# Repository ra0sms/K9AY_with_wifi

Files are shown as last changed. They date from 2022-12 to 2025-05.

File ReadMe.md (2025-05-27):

# K9AY receiving loop with Wi-Fi control

This antenna has 8 directions and switchable Load resistor

* Based on ESP8266 (esp-12 module with external Wi-Fi antenna)
* 2 loops and 8 directions
* Need only one power supply (12-13.8VDC, 500mA)
* Control via any web-browser
* Source code for Arduino IDE

More information about loop and construction details - https://ra0sms.com/k9ay-wifi-interface/

[Latest schematic version](KiCad/K9AY_switch/K9AY_switch.pdf)

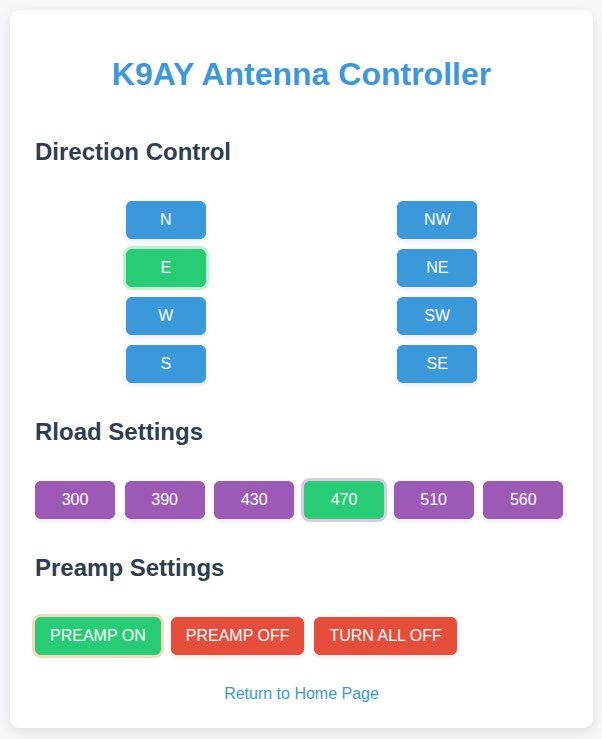
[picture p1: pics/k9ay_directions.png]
k9ay_directions


------

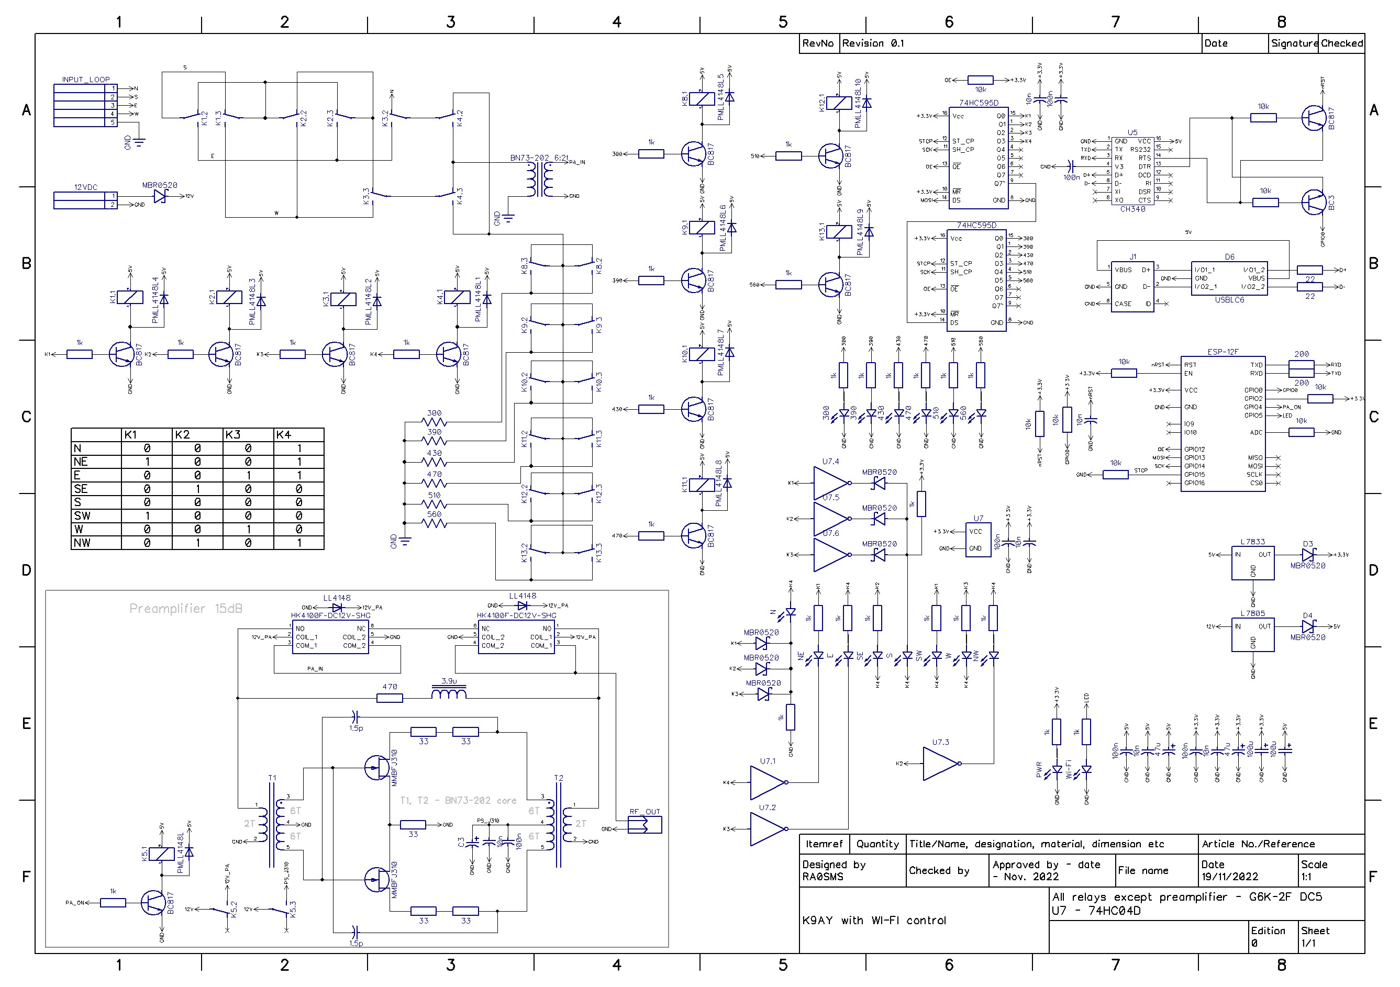
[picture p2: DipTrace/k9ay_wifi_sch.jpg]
Schematic


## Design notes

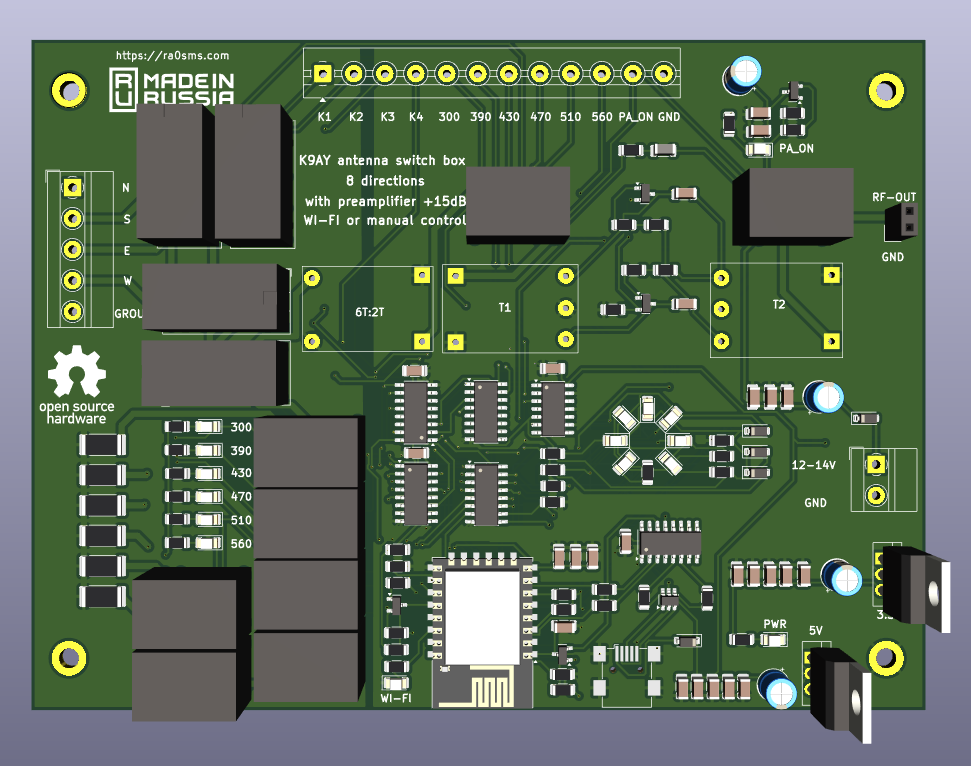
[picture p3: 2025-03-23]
KiCad/K9AY_switch/3d_1.png

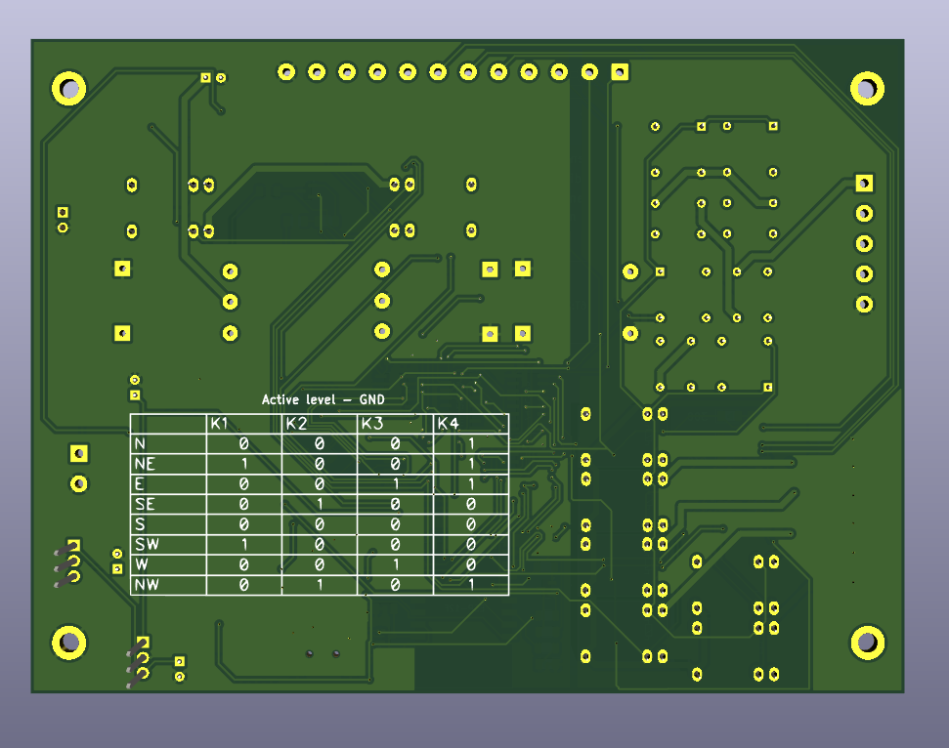
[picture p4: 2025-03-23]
KiCad/K9AY_switch/3d_2.png

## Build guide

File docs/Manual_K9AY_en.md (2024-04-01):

# Instructions for setting up K9AY control box with WI-FI interface

* External input voltage: 12V or 13.8V
* Consumption current: 200 mA
* The screw terminals **N S E W** is used to connect loops
* The screw terminal **GROUND** is used to connect radials
* WI-FI range - up to 50m when using an entry-level WI-FI router  
* Case dimensions - 170 * 120 * 55 mm. ABS plastic, degree of protection IP68, cable glands for diameter of 3 to 7 mm
* The name of the WI-FI network: **`K9AY_Loop_sn__`**  
* Access point network password: **1234567890** 
* IP address of the web server on the `K9AY_Loop_sn__` network: **192.168.4.1**  
* Links for access:
  * `192.168.4.1/wifi` – wifi settings 
  * `192.168.4.1/switch` – page for switch  
  * `192.168.4.1` – start page

Before you start setting up, your router must have **DHCP enabled!**  

When you first turn on, you need to connect the controller to your WI-FI network. To do this, you must search for available networks on your smartphone or computer. The switch creates a network `K9AY_Loop_sn__`.

After connecting the network, go to the web browser at `http://192.168.4.1/wifi`. A window with WI-FI settings will open. You must enter the name and password of your router network and click "Connect / Disconnect" button.

After that, at the page `http://192.168.4.1/wifi` you can see the IP address of the device in your WI-FI network. Now that the switch is connected to your network, you can disconnect from the `K9AY_Loop_sn__` network. Further, to access the switch's web server, use the IP address issued by your WI-FI router.

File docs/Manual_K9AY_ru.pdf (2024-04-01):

ra0sms.shop

### Инструкция по настройке контроллера управления приемной антенной K9AY с Wi-Fi интерфейсом

- Напряжение внешнего источника питания – 12(13,8)В.
- Потребляемый ток – 250 мА.
- Винтовые клеммы N S E W – для подключения взаимно перпендикулярных рамок, ориентированных на Север-Юг и Восток-Запад.
- Винтовая клемма GROUND – для подключения системы противовесов.
- Радиус действия – до 50м при использовании WI-FI роутера начального уровня
- Размеры корпуса – 170*120*55 мм. Пластик ABS, степень защиты IP68, вводы для кабеля диаметром от 3 до 7 мм
- Имя создаваемой WI-FI сети – «K9AY_Loop_sn___»
- Пароль к сети – «1234567890»
- IP адрес web сервера в сети «K9AY_Loop_sn___» – 192.168.4.1

Адреса для доступа:
192.168.4.1/wifi – страница настроек подключения в Вашей WI-FI сети 192.168.4.1/switch – страница управления контроллером 192.168.4.1 – стартовая страница веб-сервера

Перед началом настройки на вашем роутере должен быть включен DCHP!

При первом включении необходимо подключить контроллер к вашей сети WI-FI. Для этого необходимо выполнить поиск доступных сетей на смартфоне либо компьютере. Контроллер создает сеть "K9AY_Loop_sn__" пароль "1234567890".

После подключения сети необходимо перейти в веб-браузере по адресу "http://192.168.4.1/wifi" . Откроется окно с настройками WI-FI. Необходимо ввести имя и пароль вашей сети и нажать кнопку "Connect/Disconnect"

После этого по адресу "http://192.168.4.1/wifi" можно увидеть IP адрес устройства в вашей WI-FI сети. Теперь, когда контроллер подключен к вашей сети, можно отключиться от сети "K9AY_Loop_sn__". При успешном подключении к вашей WI-FI сети должен загореться светодиод “WIFI”. Далее для доступа к веб серверу контроллера используйте IP адрес, выданный вашим WI-FI роуетром.

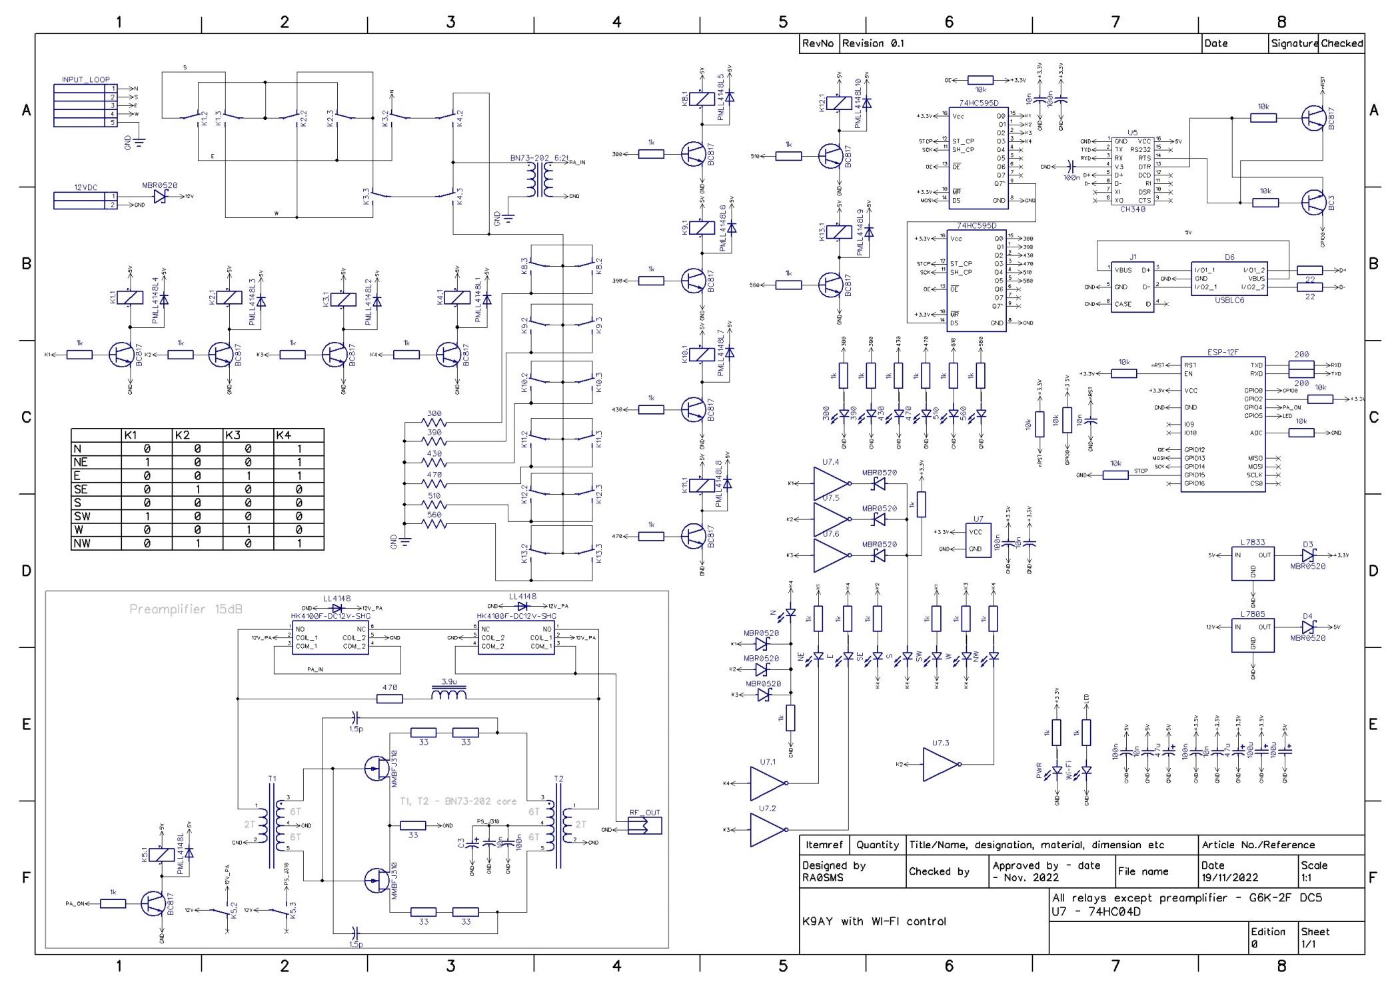
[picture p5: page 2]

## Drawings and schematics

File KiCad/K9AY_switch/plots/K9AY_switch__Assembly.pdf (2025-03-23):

## 8 directions WI-FI or manual control with preamplifier +15dB

## K9AY antenna switch box

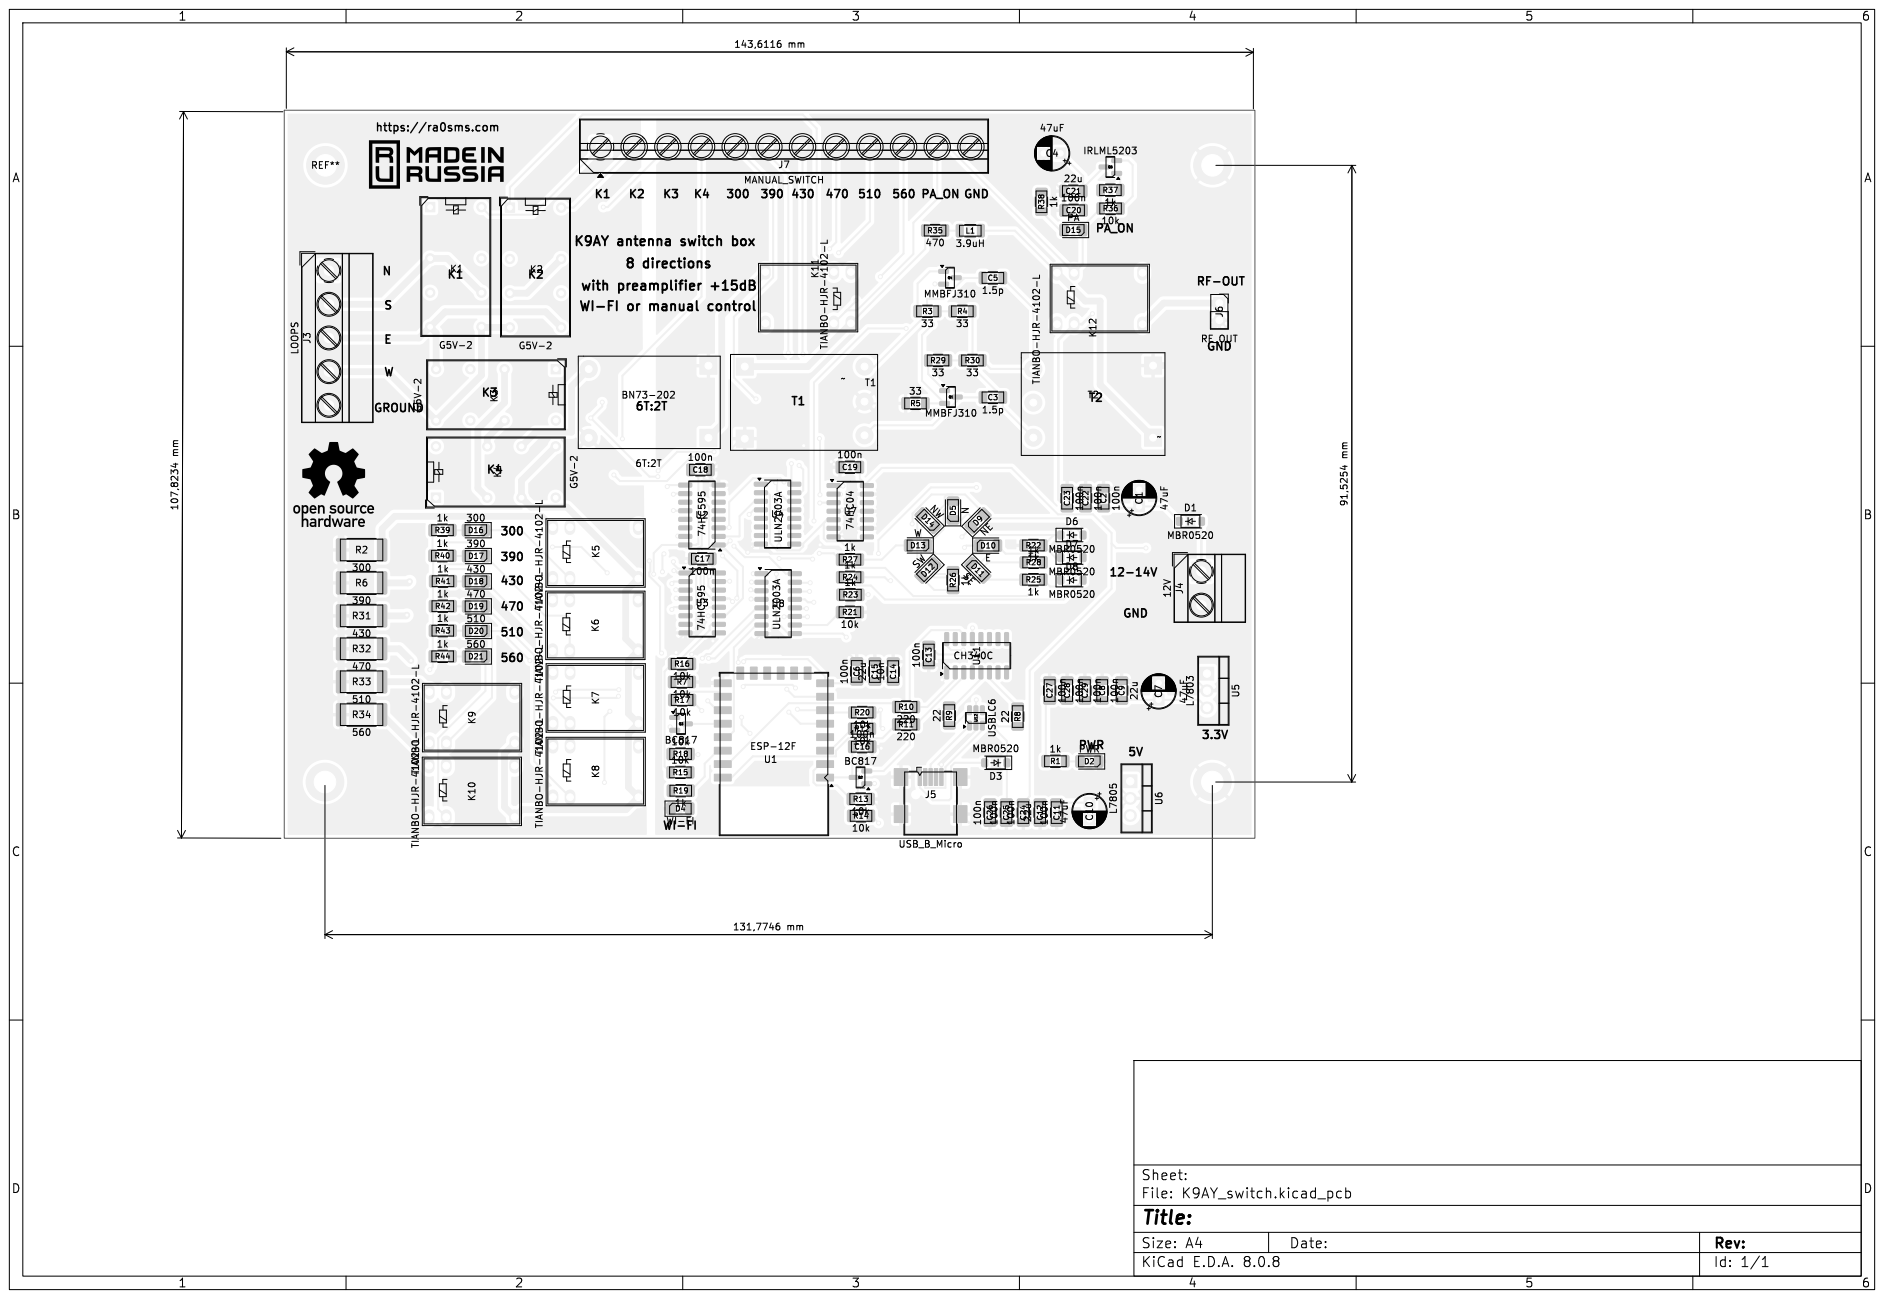
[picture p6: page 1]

1 | 2 | 3 | 4 | 5 | 6

A

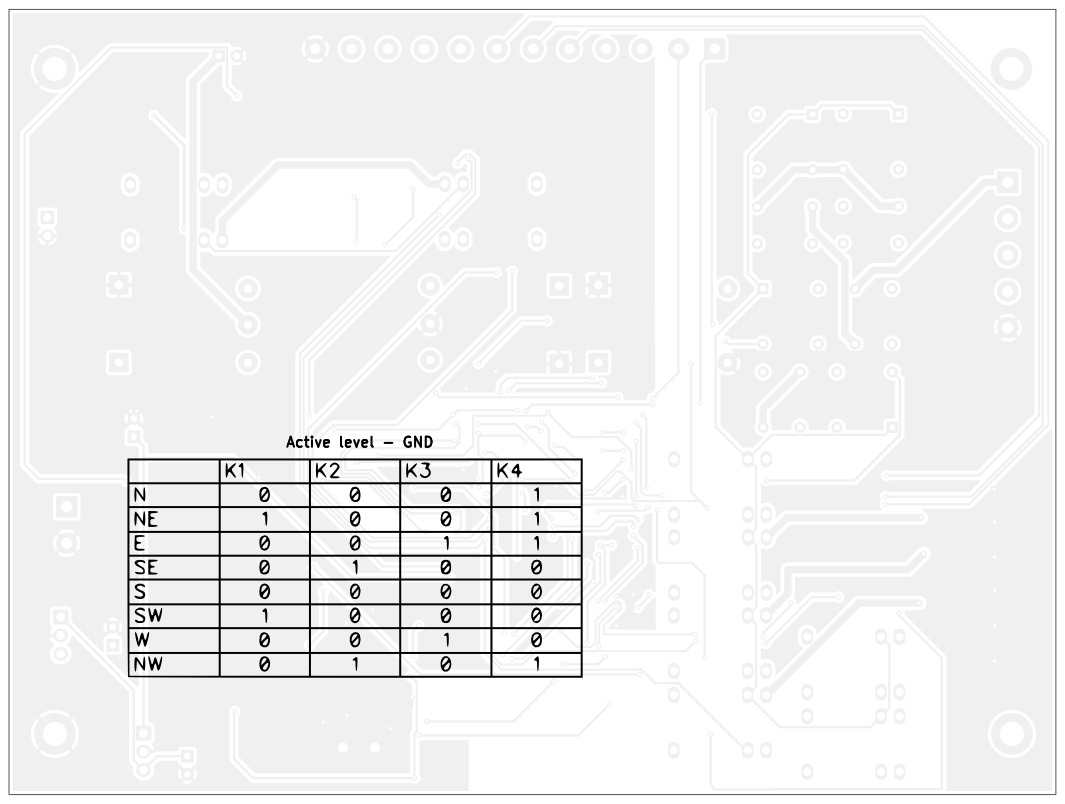
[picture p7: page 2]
D Date: KiCad; E.D.A. 8.0.8 Size: A4; Rev:

Active level - GND

Id: 1/1 Title: File: K9AY_switch.kicad_pcb Sheet:

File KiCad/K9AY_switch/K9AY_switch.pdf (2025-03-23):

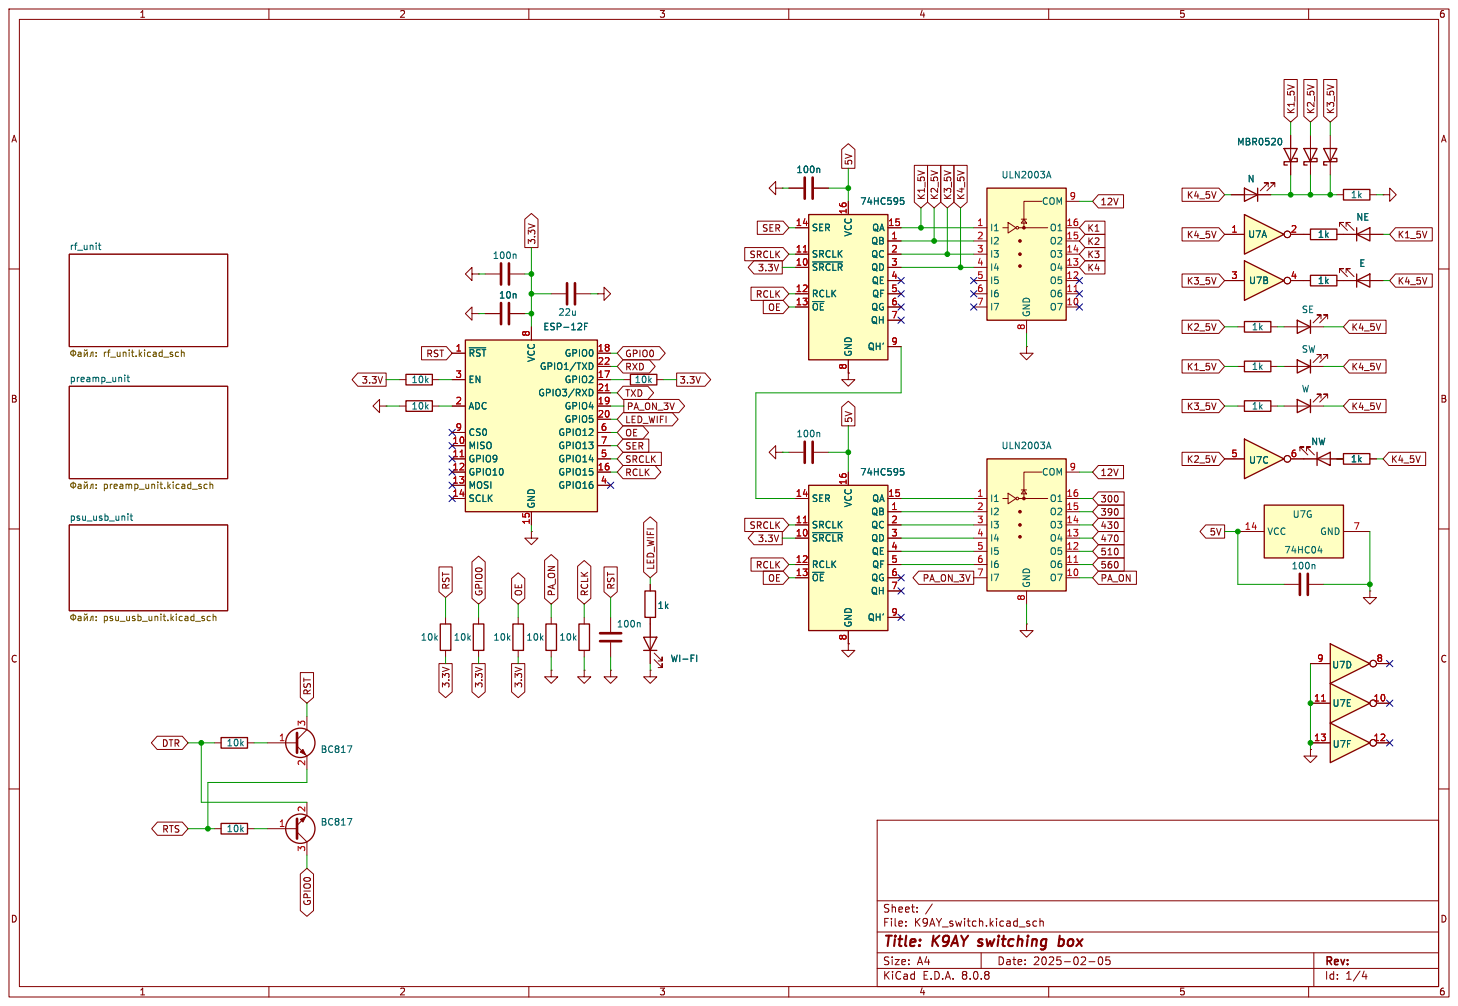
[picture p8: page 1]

2 3 BC817 QB 1 ~{SRCLR} 10 SRCLK 11 RCLK 12 ~{OE} 13 SER 14 QA 15 VCC 16 QC 2 QD 3 QE 4 QF 5 QG 6 QH 7 GND

File: K9AY_switch.kicad_sch Sheet: /
Id: 1/4 Title: K9AY switching box

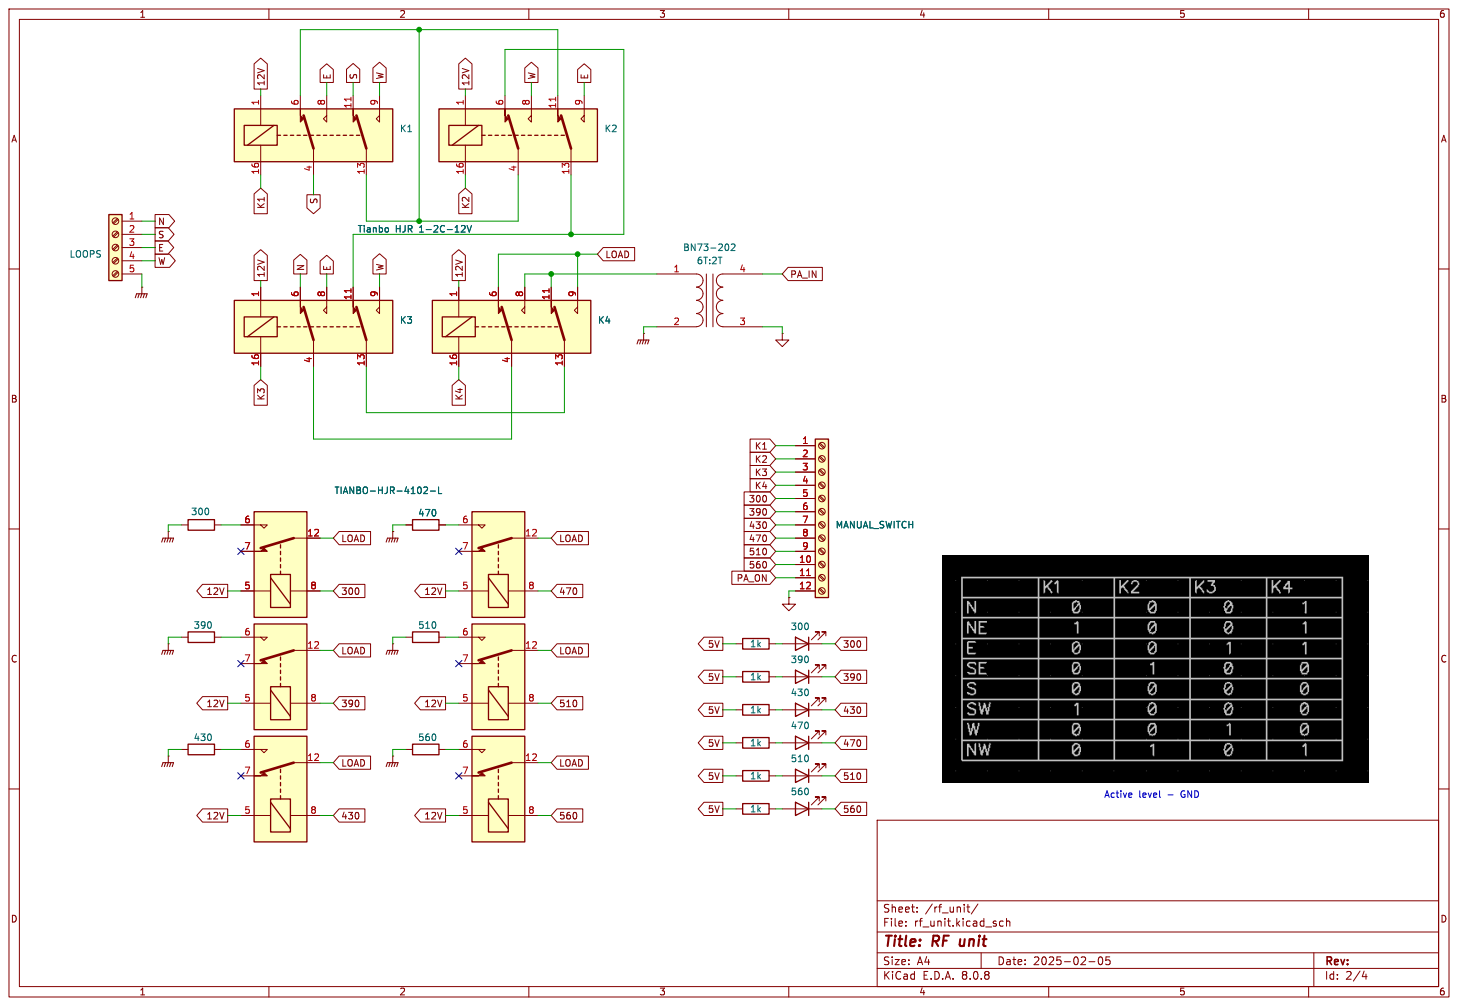
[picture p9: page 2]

Id: 2/4 Title: RF unit File: rf_unit.kicad_sch Sheet: /rf_unit/ 390

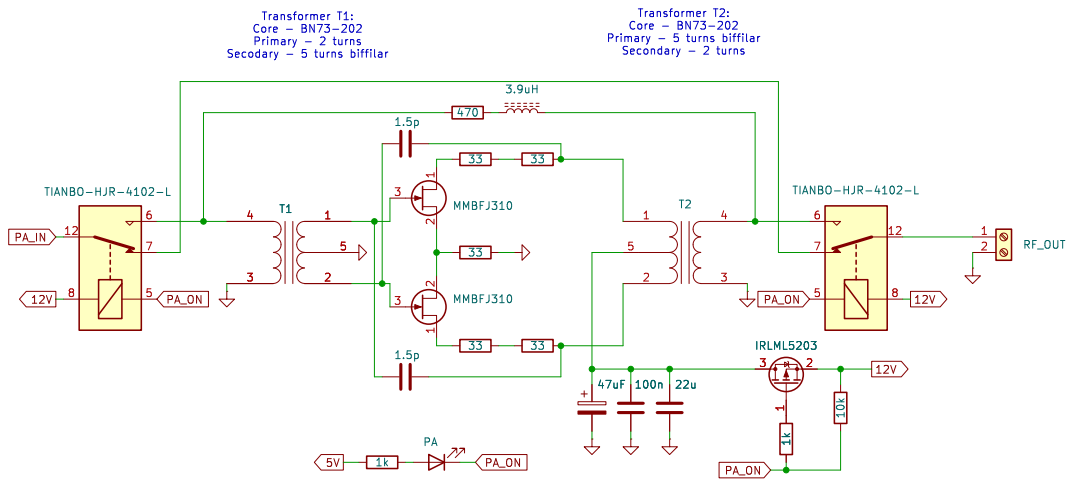
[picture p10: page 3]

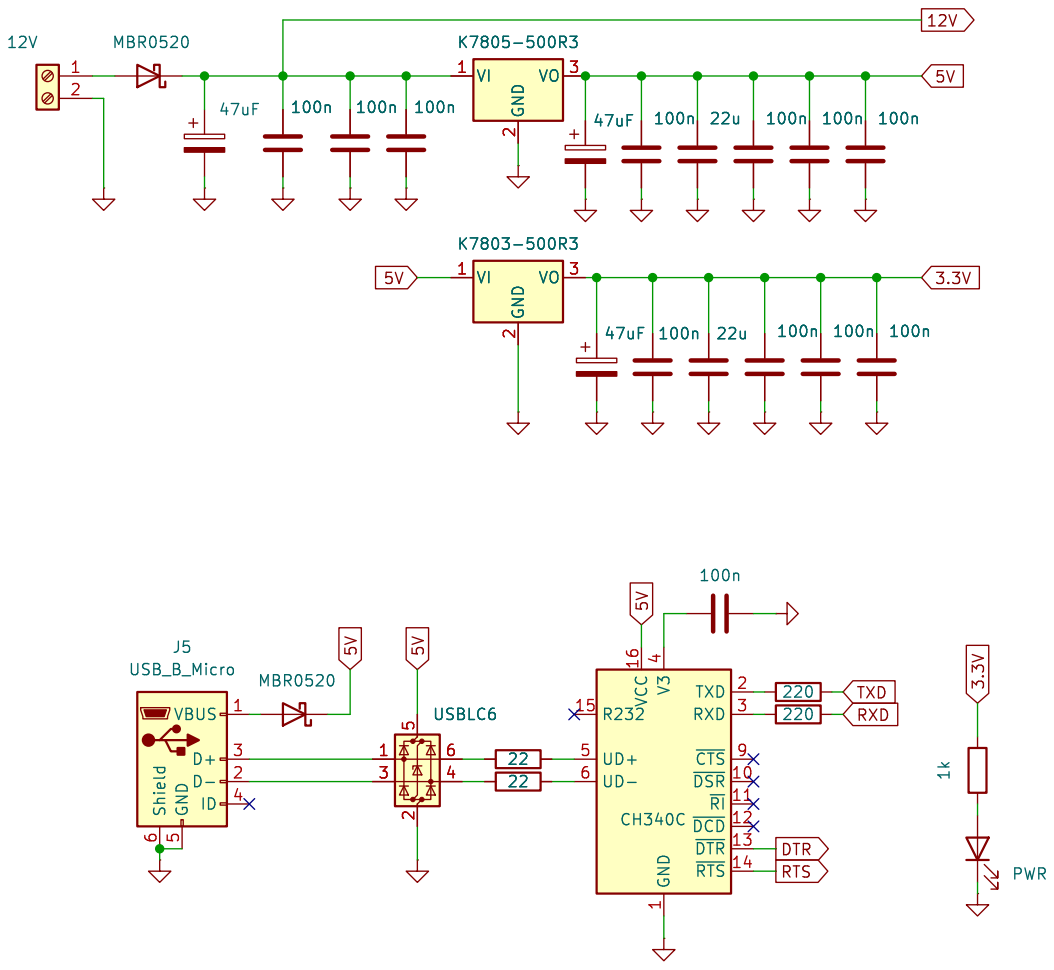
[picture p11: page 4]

1 ~{DSR} 10 ~{RI} 11 ~{DCD} 12 ~{DTR} 13 ~{RTS} 14 R232 15 VCC 16 TXD 2 RXD 3 V3

Id: 4/4 Title: Power supply and USB connection unit File: psu_usb_unit.kicad_sch Sheet: /psu_usb_unit/

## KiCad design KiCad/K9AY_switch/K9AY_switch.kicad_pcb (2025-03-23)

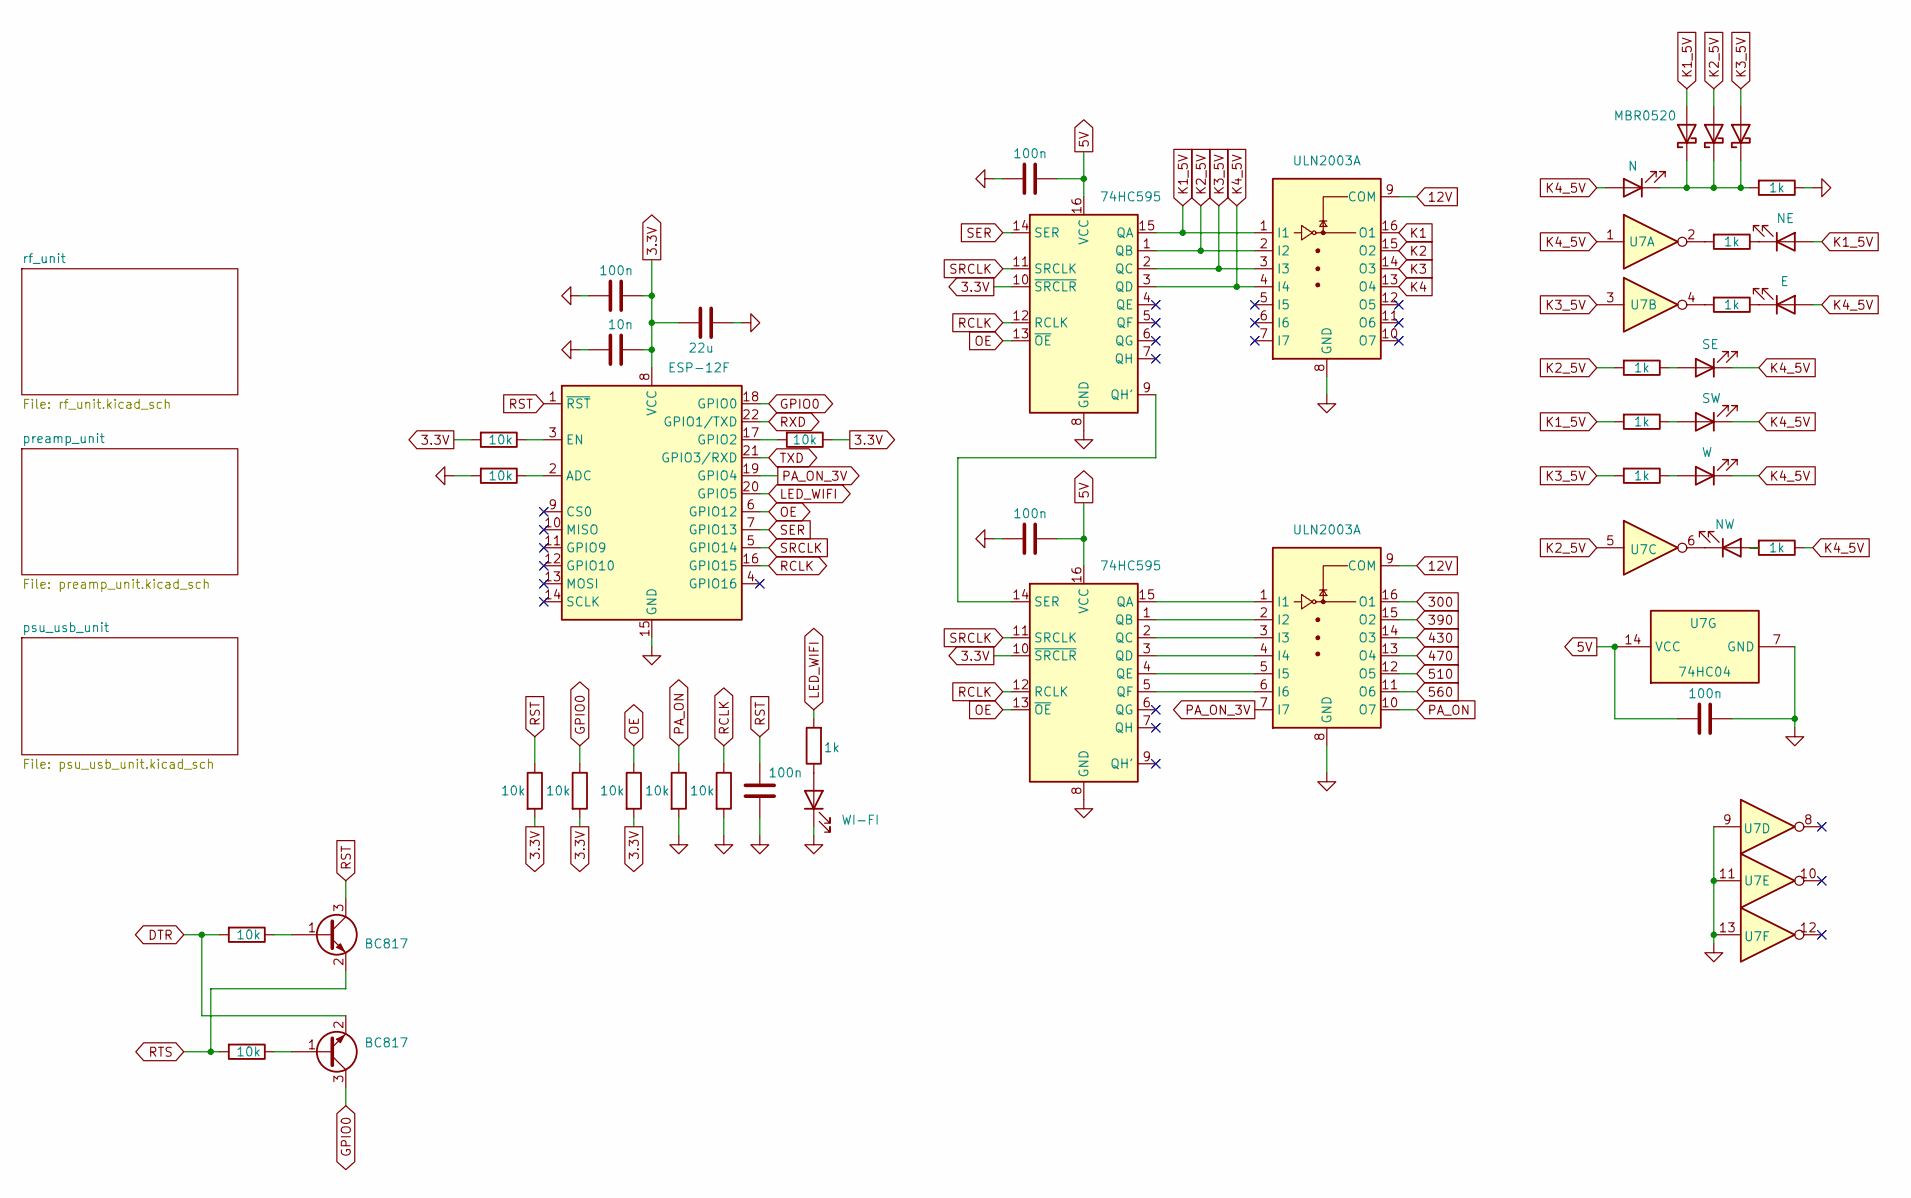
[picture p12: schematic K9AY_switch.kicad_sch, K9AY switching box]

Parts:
C6, C16, C17, C18, C19: 100n; C_1206_3216Metric
C14: 10n; C_1206_3216Metric
C15: 22u; C_1206_3216Metric
D4: WI-FI; LED_1206_3216Metric
D5: N; LED_1206_3216Metric
D6, D7, D8: MBR0520; D_SOD-123
D9: NE; LED_1206_3216Metric
D10: E; LED_1206_3216Metric
D11: SE; LED_1206_3216Metric
D12: SW; LED_1206_3216Metric
D13: W; LED_1206_3216Metric
D14: NW; LED_1206_3216Metric
Q2, Q3: BC817; SOT-23
R7, R12, R13, R14, R15, R16, R17, R18, R20, R21: 10k; R_1206_3216Metric
R19, R22, R23, R24, R25, R26, R27, R28: 1k; R_1206_3216Metric
U1: ESP-12F; ESP-12E
U2, U3: 74HC595; SOIC-16_3.9x9.9mm_P1.27mm
U4, U8: ULN2003A; SOIC-16_3.9x9.9mm_P1.27mm
U7: 74HC04; SOIC-14_3.9x8.7mm_P1.27mm

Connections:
3.3V: C6.2, C14.2, C15.2, R12.2, R14.2, R15.2, R16.1, R20.2, U1.8 (VCC), U2.10 (~SRCLR), U3.10 (~SRCLR); also elsewhere on the board
5V: C17.2, C18.2, C19.1, U2.16 (VCC), U3.16 (VCC), U7.14 (VCC); also elsewhere on the board
12V: U4.9 (COM), U8.9 (COM); also elsewhere on the board
300: U8.16 (O1); also elsewhere on the board
390: U8.15 (O2); also elsewhere on the board
430: U8.14 (O3); also elsewhere on the board
470: U8.13 (O4); also elsewhere on the board
510: U8.12 (O5); also elsewhere on the board
560: U8.11 (O6); also elsewhere on the board
DTR: Q3.2 (E), R18.2; also elsewhere on the board
GND: C6.1, C14.1, C15.1, C16.1, C17.1, C18.1, C19.2, D4.1 (K), R7.2, R13.2, R21.2, R22.1, U1.15 (GND), U2.8 (GND), U3.8 (GND), U4.8 (GND), U7.7 (GND), U7.9, U7.11, U7.13, U8.8 (GND); also elsewhere on the board
GPIO0: Q3.3 (C), R15.1, U1.18 (GPIO0)
K1: U4.16 (O1); also elsewhere on the board
K1_5V: D6.2 (A), D9.2 (A), R26.2, U2.15 (QA), U4.1 (I1)
K2: U4.15 (O2); also elsewhere on the board
K2_5V: D7.2 (A), R25.2, U2.1 (QB), U4.2 (I2), U7.5
K3: U4.14 (O3); also elsewhere on the board
K3_5V: D8.2 (A), R27.2, U2.2 (QC), U4.3 (I3), U7.3
K4: U4.13 (O4); also elsewhere on the board
K4_5V: D5.2 (A), D10.2 (A), D11.1 (K), D12.1 (K), D13.1 (K), R28.1, U2.3 (QD), U4.4 (I4), U7.1
LED_WIFI: R19.2, U1.20 (GPIO5)
unnamed: D4.2 (A), R19.1
unnamed: D5.1 (K), D6.1 (K), D7.1 (K), D8.1 (K), R22.2
unnamed: D9.1 (K), R23.1
unnamed: D10.1 (K), R24.1
unnamed: D11.2 (A), R25.1
unnamed: D12.2 (A), R26.1
unnamed: D13.2 (A), R27.1
unnamed: D14.2 (A), R28.2
unnamed: D14.1 (K), U7.6
unnamed: Q2.1 (B), R18.1
unnamed: Q3.1 (B), R17.1
unnamed: R23.2, U7.2
unnamed: R24.2, U7.4
unnamed: R13.1, U1.2 (ADC)
unnamed: R12.1, U1.3 (EN)
unnamed: R16.2, U1.17 (GPIO2)
unnamed: U2.9 (QH'), U3.14 (SER)
unnamed: U3.15 (QA), U8.1 (I1)
unnamed: U3.1 (QB), U8.2 (I2)
unnamed: U3.2 (QC), U8.3 (I3)
unnamed: U3.3 (QD), U8.4 (I4)
unnamed: U3.4 (QE), U8.5 (I5)
unnamed: U3.5 (QF), U8.6 (I6)
OE: R20.1, U1.6 (GPIO12), U2.13 (~OE), U3.13 (~OE)
PA_ON: R21.1, U8.10 (O7); also elsewhere on the board
PA_ON_3V: U1.19 (GPIO4), U8.7 (I7)
RCLK: R7.1, U1.16 (GPIO15), U2.12 (RCLK), U3.12 (RCLK)
RST: C16.2, Q2.3 (C), R14.1, U1.1 (~RST)
RTS: Q2.2 (E), R17.2; also elsewhere on the board
RXD: U1.22 (GPIO1/TXD); also elsewhere on the board
SER: U1.7 (GPIO13), U2.14 (SER)
SRCLK: U1.5 (GPIO14), U2.11 (SRCLK), U3.11 (SRCLK)
TXD: U1.21 (GPIO3/RXD); also elsewhere on the board

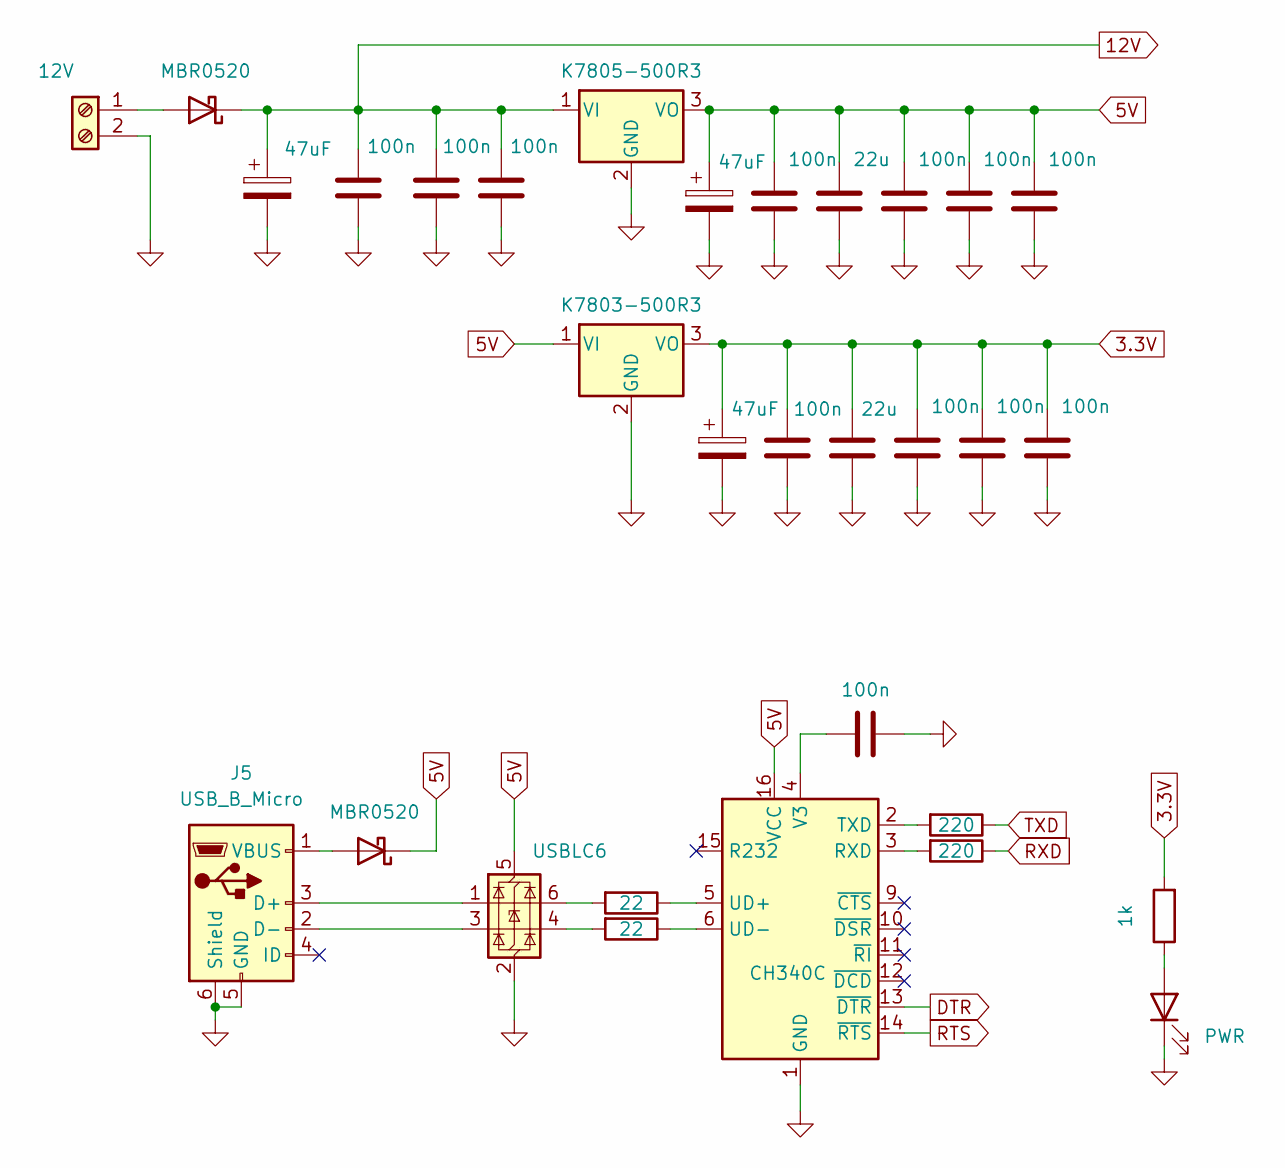
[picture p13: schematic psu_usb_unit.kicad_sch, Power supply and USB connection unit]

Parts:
C1, C7, C10: 47uF; CP_Radial_D5.0mm_P2.50mm
C2, C8, C11, C13, C22, C23, C24, C25, C26, C27, C28, C29: 100n; C_1206_3216Metric
C9, C12: 22u; C_1206_3216Metric
D1, D3: MBR0520; D_SOD-123
D2: PWR; LED_1206_3216Metric
J4: 12V; TerminalBlock_MetzConnect_Type011_RT05502HBWC_1x02_P5.00mm_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
J5: USB_B_Micro; USB_Mini-B_Wuerth_65100516121_Horizontal
R1: 1k; R_1206_3216Metric
R8, R9: 22; R_1206_3216Metric
R10, R11: 220; R_1206_3216Metric
U5: K7803-500R3; TO-220-3_Vertical
U6: K7805-500R3; TO-220-3_Vertical
U11: CH340C; SOIC-16_3.9x9.9mm_P1.27mm
U12: USBLC6; SOT-23-6

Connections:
3.3V: C7.1, C8.1, C9.1, C27.1, C28.1, C29.1, R1.2, U5.3 (VO); also elsewhere on the board
5V: C10.1, C11.1, C12.1, C24.1, C25.1, C26.1, D3.1 (K), U5.1 (VI), U6.3 (VO), U11.16 (VCC), U12.5 (VBUS); also elsewhere on the board
12V: C1.1, C2.1, C22.1, C23.1, D1.1 (K), U6.1 (VI); also elsewhere on the board
DTR: U11.13 (~DTR); also elsewhere on the board
GND: C1.2, C2.2, C7.2, C8.2, C9.2, C10.2, C11.2, C12.2, C13.2, C22.2, C23.2, C24.2, C25.2, C26.2, C27.2, C28.2, C29.2, D2.1 (K), J4.2, J5.5 (GND), J5.6 (Shield), U5.2 (GND), U6.2 (GND), U11.1 (GND), U12.2 (GND); also elsewhere on the board
unnamed: D1.2 (A), J4.1
unnamed: D2.2 (A), R1.1
unnamed: D3.2 (A), J5.1 (VBUS)
unnamed: J5.3 (D+), U12.1 (I/O1)
unnamed: J5.2 (D-), U12.3 (I/O2)
unnamed: R8.2, U12.4 (I/O2)
unnamed: R9.2, U12.6 (I/O1)
unnamed: R11.2, U11.3 (RXD)
unnamed: R10.2, U11.2 (TXD)
unnamed: R9.1, U11.5 (UD+)
unnamed: R8.1, U11.6 (UD-)
unnamed: C13.1, U11.4 (V3)
RTS: U11.14 (~RTS); also elsewhere on the board
RXD: R11.1; also elsewhere on the board
TXD: R10.1; also elsewhere on the board

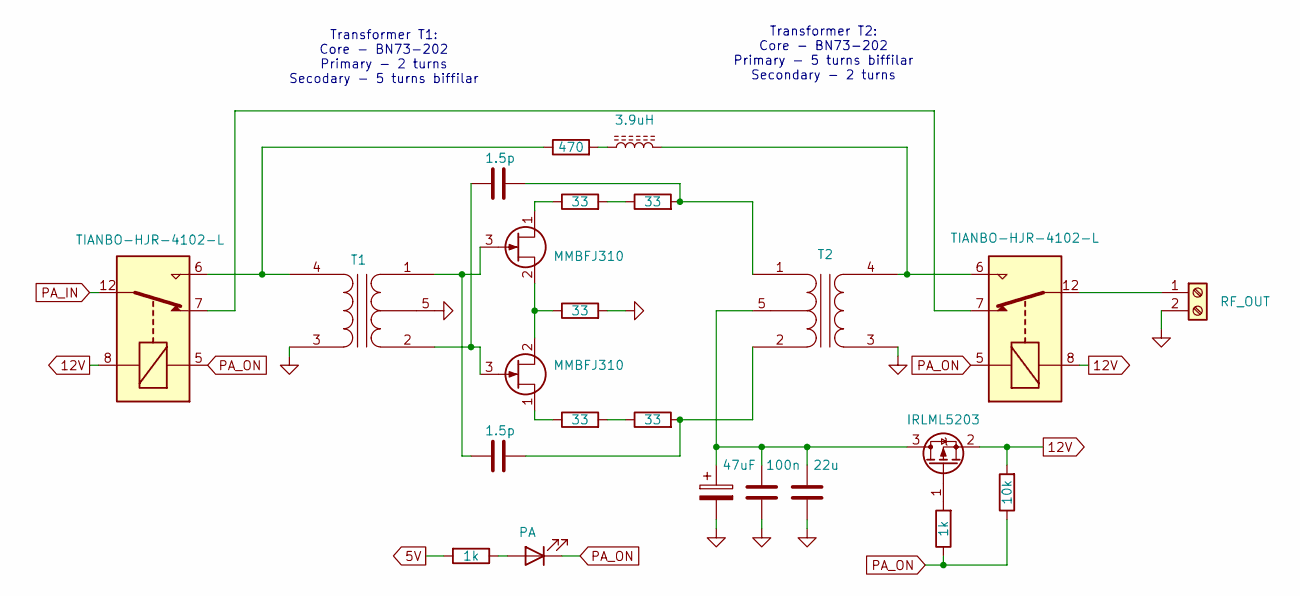
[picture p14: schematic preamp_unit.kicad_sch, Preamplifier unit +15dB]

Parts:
C3, C5: 1.5p; C_1206_3216Metric
C4: 47uF; CP_Radial_D5.0mm_P2.50mm
C20: 100n; C_1206_3216Metric
C21: 22u; C_1206_3216Metric
D15: PA; LED_1206_3216Metric
J6: RF_OUT; PinSocket_1x02_P2.54mm_Vertical
K11, K12: TIANBO-HJR-4102-L; Relay_SPDT_HJR-4102
L1: 3.9uH; L_1206_3216Metric
Q1, Q4: MMBFJ310; SOT-23
Q5: IRLML5203; SOT-23
R3, R4, R5, R29, R30: 33; R_1206_3216Metric
R35: 470; R_1206_3216Metric
R36: 10k; R_1206_3216Metric
R37, R38: 1k; R_1206_3216Metric
T1, T2: Transformer_J310

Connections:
5V: R38.2; also elsewhere on the board
12V: K11.8, K12.8, Q5.2 (S), R36.2; also elsewhere on the board
GND: C4.2, C20.2, C21.2, J6.2, R5.2, T1.3 (SA), T1.5, T2.3 (SA); also elsewhere on the board
unnamed: D15.2 (A), R38.1
unnamed: J6.1, K12.12
unnamed: K11.7, K12.7
unnamed: L1.1, R35.2
unnamed: Q1.1 (D), R29.1
unnamed: C3.1, Q1.3 (G), T1.1 (AA)
unnamed: Q1.2 (S), Q4.2 (S), R5.1
unnamed: Q4.1 (D), R3.1
unnamed: C5.1, Q4.3 (G), T1.2 (AB)
unnamed: C4.1, C20.1, C21.1, Q5.3 (D), T2.5
unnamed: Q5.1 (G), R37.2
unnamed: R3.2, R4.1
unnamed: R29.2, R30.1
unnamed: K11.6, R35.1, T1.4 (SB)
unnamed: C5.2, R30.2, T2.1 (AA)
unnamed: C3.2, R4.2, T2.2 (AB)
unnamed: K12.6, L1.2, T2.4 (SB)
PA_IN: K11.12; also elsewhere on the board
PA_ON: D15.1 (K), K11.5, K12.5, R36.1, R37.1; also elsewhere on the board

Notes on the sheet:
Transformer T1: Core - BN73-202 Primary - 2 turns Secodary - 5 turns biffilar
Transformer T2: Core - BN73-202 Primary - 5 turns biffilar Secondary - 2 turns

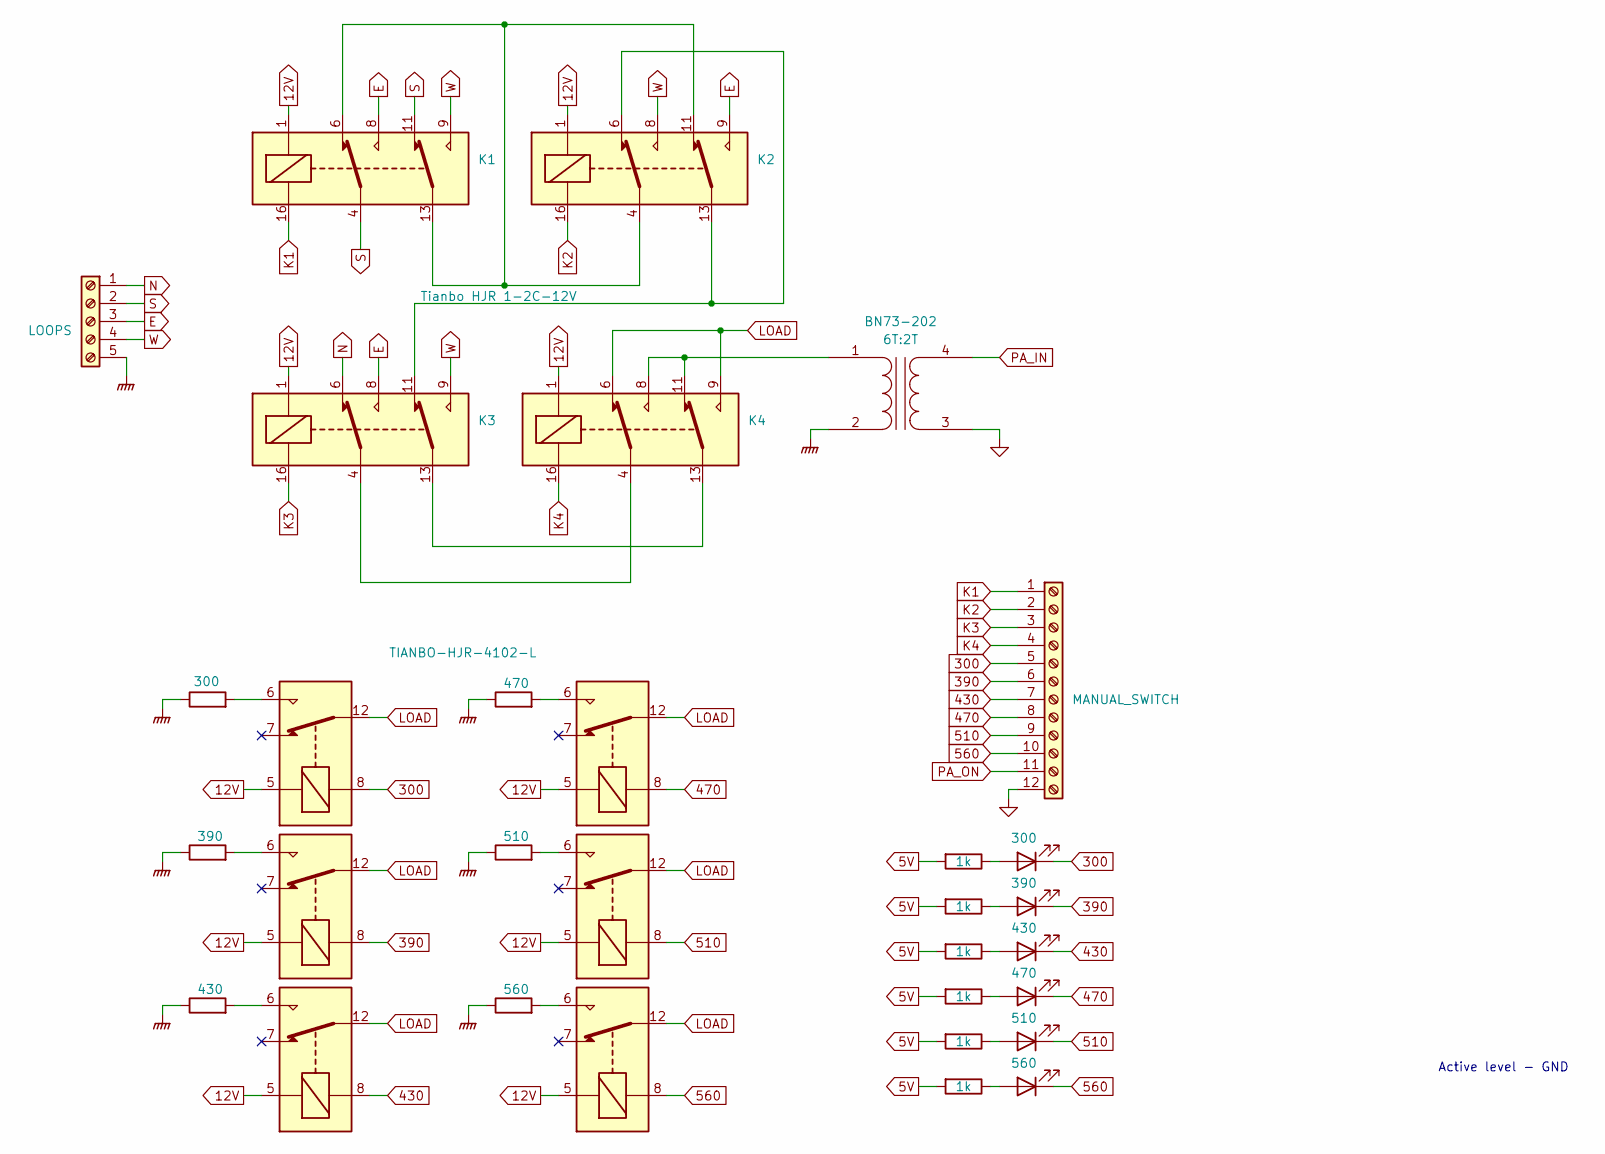
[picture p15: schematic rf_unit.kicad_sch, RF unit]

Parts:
BN73-202: 6T:2T; Transformer_BN73-202
D16: 300; LED_1206_3216Metric
D17: 390; LED_1206_3216Metric
D18: 430; LED_1206_3216Metric
D19: 470; LED_1206_3216Metric
D20: 510; LED_1206_3216Metric
D21: 560; LED_1206_3216Metric
J3: LOOPS; TerminalBlock_MetzConnect_Type011_RT05505HBWC_1x05_P5.00mm_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
J7: MANUAL_SWITCH; TerminalBlock_MaiXu_MX126-5.0-12P_1x12_P5.00mm
K1, K2, K4: G5V-2; Relay_DPDT_Omron_G5V-2
K3: Tianbo HJR 1-2C-12V; Relay_DPDT_Omron_G5V-2
K5, K6, K7, K8, K9, K10: TIANBO-HJR-4102-L; Relay_SPDT_HJR-4102
R2: 300; R_2512_6332Metric_Pad1.40x3.35mm_HandSolder
R6: 390; R_2512_6332Metric_Pad1.40x3.35mm_HandSolder
R31: 430; R_2512_6332Metric_Pad1.40x3.35mm_HandSolder
R32: 470; R_2512_6332Metric_Pad1.40x3.35mm_HandSolder
R33: 510; R_2512_6332Metric_Pad1.40x3.35mm_HandSolder
R34: 560; R_2512_6332Metric_Pad1.40x3.35mm_HandSolder
R39, R40, R41, R42, R43, R44: 1k; R_1206_3216Metric

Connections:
5V: R39.2, R40.2, R41.2, R42.2, R43.2, R44.2; also elsewhere on the board
12V: K1.1, K2.1, K3.1, K4.1, K5.5, K6.5, K7.5, K8.5, K9.5, K10.5; also elsewhere on the board
300: D16.1 (K), J7.5, K5.8; also elsewhere on the board
390: D17.1 (K), J7.6, K6.8; also elsewhere on the board
430: D18.1 (K), J7.7, K7.8; also elsewhere on the board
470: D19.1 (K), J7.8, K8.8; also elsewhere on the board
510: D20.1 (K), J7.9, K9.8; also elsewhere on the board
560: D21.1 (K), J7.10, K10.8; also elsewhere on the board
E: J3.3, K1.8, K2.9, K3.8
GND: BN73-202.3 (SA), J7.12; also elsewhere on the board
GNDPWR: BN73-202.2 (AB), J3.5, R2.1, R6.1, R31.1, R32.1, R33.1, R34.1
K1: J7.1, K1.16; also elsewhere on the board
K2: J7.2, K2.16; also elsewhere on the board
K3: J7.3, K3.16; also elsewhere on the board
K4: J7.4, K4.16; also elsewhere on the board
LOAD: K4.6, K4.9, K5.12, K6.12, K7.12, K8.12, K9.12, K10.12
N: J3.1, K3.6
unnamed: BN73-202.1 (AA), K4.8, K4.11
unnamed: D16.2 (A), R39.1
unnamed: D17.2 (A), R40.1
unnamed: D18.2 (A), R41.1
unnamed: D19.2 (A), R42.1
unnamed: D20.2 (A), R43.1
unnamed: D21.2 (A), R44.1
unnamed: K1.6, K1.13, K2.4, K2.11
unnamed: K2.6, K2.13, K3.11
unnamed: K3.4, K4.4
unnamed: K3.13, K4.13
unnamed: K5.6, R2.2
unnamed: K6.6, R6.2
unnamed: K7.6, R31.2
unnamed: K8.6, R32.2
unnamed: K9.6, R33.2
unnamed: K10.6, R34.2
PA_IN: BN73-202.4 (SB); also elsewhere on the board
PA_ON: J7.11; also elsewhere on the board
S: J3.2, K1.4, K1.11
W: J3.4, K1.9, K2.8, K3.9

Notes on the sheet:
Active level - GND

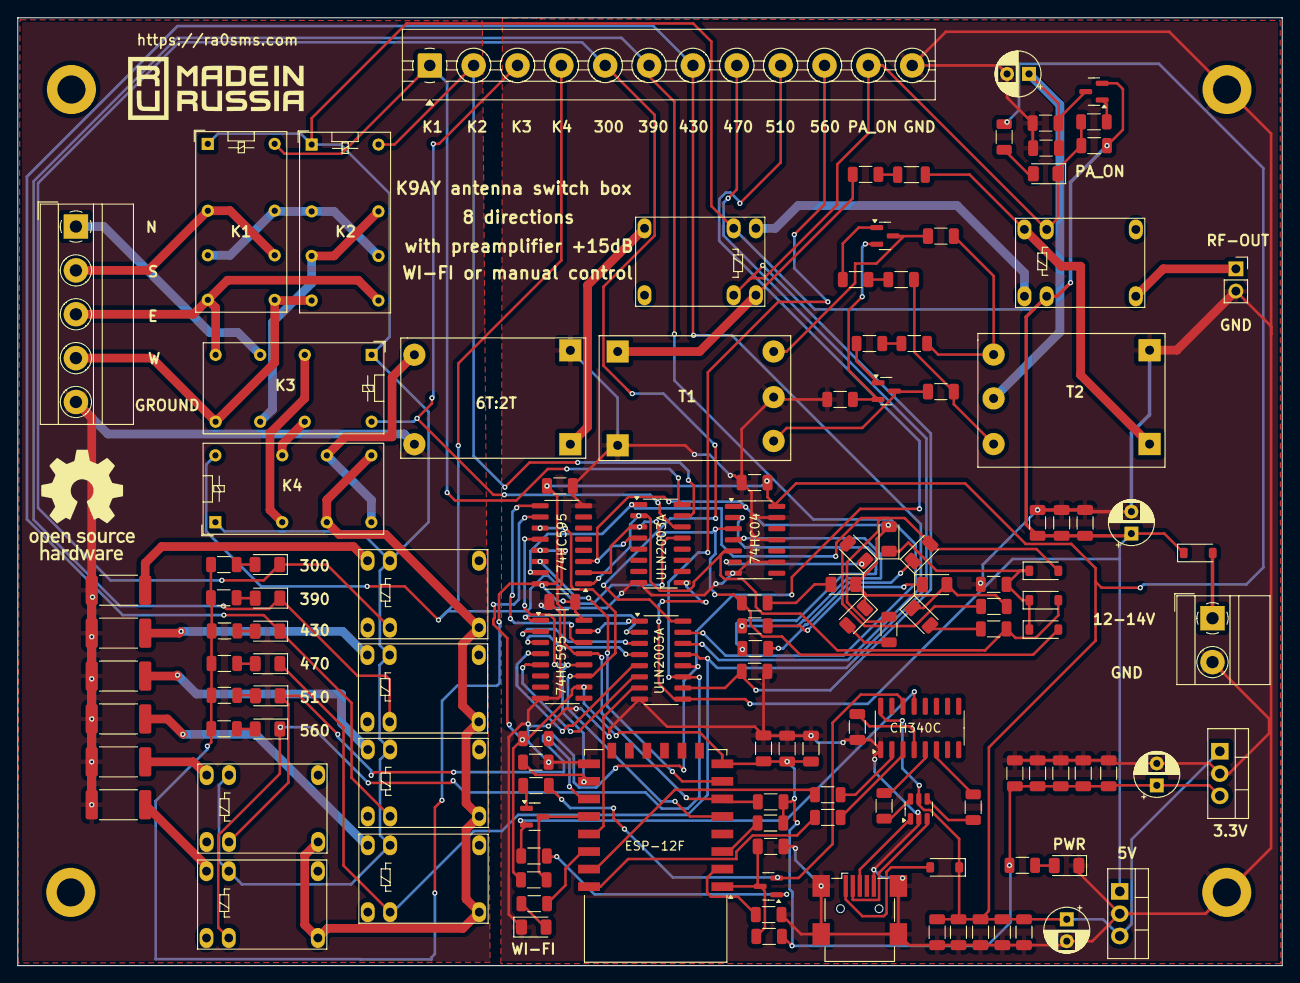
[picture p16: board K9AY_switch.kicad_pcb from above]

Board: 2 copper layers, 144.1 x 108.1 mm, 130 parts (0 on the bottom side), 107 nets.

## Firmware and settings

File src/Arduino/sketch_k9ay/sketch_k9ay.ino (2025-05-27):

/*
K9AY loop control box
ESP12 module
Irkutsk, December 2022
ra0sms@bk.ru

27052025 - Update for web-interface (CSS)
*/

#include <Arduino.h>
#include <ESP8266WiFi.h>
#include <WiFiClient.h>
#include <ESP8266WebServer.h>
#include <DNSServer.h>
#include <ESP8266mDNS.h>
#include <EEPROM.h>
#include <SPI.h>
//**********************************************
const char *softAP_ssid = "K9AY_Loop_sn044";
const char *softAP_password = "1234567890";
const char *myHostname = "esp8266";
//*********************************************
void buildXML ();
void saveLabels ();
void saveCredentials ();
void CheckStat ();
void handleXML ();
void buildJavascript ();
void handleSwitch ();
void handleRoot ();
void handleLabel (); 
void handleLabelSave ();
void loadLabels ();
void handleWifi ();
void handleNotFound ();
void handleWifiSave ();
void loadCredentials ();
void turnOffAll ();
void connectWifi ();
 //********************************************
char ssid[32] = "";
char password[32] = "";
char label0[32] ="N";
char label1[32] ="NE";
char label2[32] ="E";
char label3[32] ="SE";
char label4[32] ="S";
char label5[32] ="SW";
char label6[32] ="W";
char label7[32] ="NW";
char label8[32] ="";
char label300[32] = "300";
char label390[32] = "390";
char label430[32] = "430";
char label470[32] = "470";
char label510[32] = "510";
char label560[32] = "560";
char labelpa[32] = "+15dB";
String currentlabel ="";
String currentRload ="";
String currentPa =" ";
String webPage = "";
String webPage2 = "";
String ourPage = "";
String Page3="";
String javaScript, XML;
//********************************************* 
int PA_pin = 4;
int LED_pin = 5;
int OE_pin = 12;
/***SPI*/
int latchPin = 15;
int clockPin = 14;
int dataPin = 13;
/*******/
char stat[8] =  "";
int tim = 0;
int sec = 0;
int minute = 0;
int hour = 0;
int day = 0;
int flagAP=0;
int flag_off=0;
int out1=0;
int out2=0;
//*********************************************
const byte DNS_PORT = 53;
DNSServer dnsServer;
ESP8266WebServer server(80);
IPAddress apIP(192, 168, 4, 1);
IPAddress netMsk(255, 255, 255, 0);
boolean connect;
unsigned long lastConnectTry = 0;
unsigned int status = WL_IDLE_STATUS;
//*********************************************

void CheckStat ()
{
  currentlabel ="";
  if (stat[0] == '1') currentlabel+=String(label0)+ " ";
  if (stat[1] == '1') currentlabel+=String(label1)+ " ";
  if (stat[2] == '1') currentlabel+=String(label2)+ " ";
  if (stat[3] == '1') currentlabel+=String(label3)+ " ";
  if (stat[4] == '1') currentlabel+=String(label4)+ " ";
  if (stat[5] == '1') currentlabel+=String(label5)+ " ";
  if (stat[6] == '1') currentlabel+=String(label6)+ " ";
  if (stat[7] == '1') currentlabel+=String(label7);
}

void handleXML() {
  buildXML();
  server.send(200, "text/xml", XML);
}


void buildJavascript() {
  javaScript = R"(
<SCRIPT>
var xmlHttp = createXmlHttpObject();

function createXmlHttpObject() {
  if (window.XMLHttpRequest) {
    xmlHttp = new XMLHttpRequest();
  } else {
    xmlHttp = new ActiveXObject('Microsoft.XMLHTTP');
  }
  return xmlHttp;
}

function process() {
  if (xmlHttp.readyState == 0 || xmlHttp.readyState == 4) {
    xmlHttp.open('PUT', 'xml', true);
    xmlHttp.onreadystatechange = handleServerResponse;
    xmlHttp.send(null);
  }
  setTimeout('process()', 100);
}

function handleServerResponse() {
  if (xmlHttp.readyState == 4 && xmlHttp.status == 200) {
    var xmlResponse = xmlHttp.responseXML;
    var xmldoc = xmlResponse.getElementsByTagName('response');
    var message = xmldoc[0].firstChild.nodeValue;
    document.getElementById('runtime').innerHTML = message;
  }
}
</SCRIPT>
)";
}

void buildXML() {
  XML = "<?xml version='1.0'?><response>";
  XML += currentlabel + " " + currentRload + " " + currentPa;
  XML += "</response>";
}


void handleSwitch() {
  buildJavascript();
  digitalWrite(clockPin, LOW);

  String webPage = String(R"(
<!DOCTYPE HTML>
<html>
<head>
  <title>K9AY Antenna Controller</title>
  <meta name="viewport" content="width=device-width, initial-scale=1">
  <style>
    :root {
      --primary: #3498db;
      --secondary: #2ecc71;
      --danger: #e74c3c;
      --dark: #2c3e50;
      --light: #ecf0f1;
    }
    
    body {
      font-family: 'Roboto', sans-serif;
      background-color: #f5f7fa;
      margin: 0;
      padding: 20px;
      color: var(--dark);
    }
    
    .container {
      max-width: 800px;
      margin: 0 auto;
      background: white;
      border-radius: 10px;
      box-shadow: 0 4px 12px rgba(0,0,0,0.1);
      padding: 25px;
    }
    
    h1 {
      color: var(--primary);
      text-align: center;
      margin-bottom: 25px;
    }
    
    h2 {
      color: var(--dark);
      margin-top: 20px;
    }
    
    .status-display {
      background: var(--light);
      padding: 15px;
      border-radius: 8px;
      text-align: center;
      font-size: 18px;
      margin-bottom: 20px;
      font-weight: 500;
    }
    
    .control-panel {
      display: flex;
      flex-direction: column;
      gap: 15px;
    }
    
    .direction-grid {
      display: grid;
      grid-template-columns: repeat(2, 1fr);
      gap: 10px;
      justify-items: center;
    }
    
    .btn {
      border: none;
      color: white;
      padding: 10px 15px;
      text-align: center;
      text-decoration: none;
      display: inline-block;
      font-size: 16px;
      font-weight: 500;
      border-radius: 6px;
      cursor: pointer;
      transition: all 0.3s ease;
      min-width: 80px;
      box-shadow: 0 2px 5px rgba(0,0,0,0.1);
    }
    
    .btn:hover {
      transform: translateY(-2px);
      box-shadow: 0 4px 8px rgba(0,0,0,0.15);
    }
    
    .btn:active {
      transform: translateY(0);
    }
    
    .btn-direction {
      background-color: var(--primary);
    }
    
    .btn-direction.active {
      background-color: var(--secondary);
      box-shadow: 0 0 0 3px rgba(46, 204, 113, 0.3);
    }
    
    .btn-rload {
      background-color: #9b59b6;
    }
    
    .btn-rload.active {
      background-color: var(--secondary);
      box-shadow: 0 0 0 3px rgba(142, 68, 173, 0.3);
    }
    
    .btn-pa {
      background-color: #f39c12;
    }
    
    .btn-pa.active {
      background-color: var(--secondary);
      box-shadow: 0 0 0 3px rgba(230, 126, 34, 0.3);
    }
    
    .btn-off {
      background-color: var(--danger);
    }
    
    .options-grid {
      display: grid;
      grid-template-columns: repeat(auto-fit, minmax(80px, 1fr));
      gap: 5px;
    }
    
    .footer {
      text-align: center;
      margin-top: 30px;
      color: #7f8c8d;
    }
    
    .footer a {
      color: var(--primary);
      text-decoration: none;
    }
    
    .footer a:hover {
      text-decoration: underline;
    }
    
    @media (max-width: 600px) {
      .direction-grid {
        grid-template-columns: repeat(2, 1fr);
      }
    }
  </style>
</head>
)");

  webPage += javaScript;
  webPage += String(R"(
<body>
  <div class="container">
    <h1>K9AY Antenna Controller</h1>
      <div class="control-panel">
      <h2>Direction Control</h2>
      <div class="direction-grid">
        <a href="setN"><button class="btn btn-direction)") + 
        (currentlabel == "N" ? " active\"" : "\"") + String(R"(>N</button></a>
        <a href="setNW"><button class="btn btn-direction)") + 
        (currentlabel == "NW" ? " active\"" : "\"") + String(R"(>NW</button></a>
        <a href="setE"><button class="btn btn-direction)") + 
        (currentlabel == "E" ? " active\"" : "\"") + String(R"(>E</button></a>
        <a href="setNE"><button class="btn btn-direction)") + 
        (currentlabel == "NE" ? " active\"" : "\"") + String(R"(>NE</button></a>
        <a href="setW"><button class="btn btn-direction)") + 
        (currentlabel == "W" ? " active\"" : "\"") + String(R"(>W</button></a>
        <a href="setSW"><button class="btn btn-direction)") + 
        (currentlabel == "SW" ? " active\"" : "\"") + String(R"(>SW</button></a>
        <a href="setS"><button class="btn btn-direction)") + 
        (currentlabel == "S" ? " active\"" : "\"") + String(R"(>S</button></a>
        <a href="setSE"><button class="btn btn-direction)") + 
        (currentlabel == "SE" ? " active\"" : "\"") + String(R"(>SE</button></a>
      </div>
      
      <h2>Rload Settings</h2>
      <div class="options-grid">
        <a href="set300"><button class="btn btn-rload)") + 
        (currentRload == " 300 Ohm" ? " active\"" : "\"") + String(R"(>300</button></a>
        <a href="set390"><button class="btn btn-rload)") + 
        (currentRload == " 390 Ohm" ? " active\"" : "\"") + String(R"(>390</button></a>
        <a href="set430"><button class="btn btn-rload)") + 
        (currentRload == " 430 Ohm" ? " active\"" : "\"") + String(R"(>430</button></a>
        <a href="set470"><button class="btn btn-rload)") + 
        (currentRload == " 470 Ohm" ? " active\"" : "\"") + String(R"(>470</button></a>
        <a href="set510"><button class="btn btn-rload)") + 
        (currentRload == " 510 Ohm" ? " active\"" : "\"") + String(R"(>510</button></a>
        <a href="set560"><button class="btn btn-rload)") + 
        (currentRload == " 560 Ohm" ? " active\"" : "\"") + String(R"(>560</button></a>
      </div>
      
      <h2>Preamp Settings</h2>
      <div style="display: flex; gap: 10px;">
        <a href="setPa"><button class="btn btn-pa)") + 
        (currentPa == " +15dB" ? " active\"" : "\"") + String(R"(>PREAMP ON</button></a>
        <a href="resetPa"><button class="btn btn-off)") + 
        (currentPa == " " ? " active\"" : "\"") + String(R"(>PREAMP OFF</button></a>
        <a href="resetAll"><button class="btn btn-off">TURN ALL OFF</button></a>
      </div>
    </div>
    
    <div class="footer">
      <a href="/">Return to Home Page</a>
    </div>
  </div>
</body>
</html>
)");

  server.send(200, "text/html", webPage);
}




void handleRoot() {
  // Запрещаем кэширование страницы
  server.sendHeader("Cache-Control", "no-cache, no-store, must-revalidate");
  server.sendHeader("Pragma", "no-cache");
  server.sendHeader("Expires", "-1");
  
  
  // Формируем HTML страницу
  String Page = String(R"(
<!DOCTYPE html>
<html lang="en">
<head>
  <meta charset="UTF-8">
  <meta name="viewport" content="width=device-width, initial-scale=1.0">
  <title>K9AY Loop Controller</title>
  <style>
    :root {
      --primary: #3498db;
      --secondary: #2ecc71;
      --dark: #2c3e50;
      --light: #ecf0f1;
    }
    
    body {
      font-family: 'Segoe UI', Tahoma, Geneva, Verdana, sans-serif;
      line-height: 1.6;
      color: var(--dark);
      max-width: 800px;
      margin: 0 auto;
      padding: 20px;
      background-color: #f5f7fa;
    }
    
    header {
      text-align: center;
      margin-bottom: 30px;
    }
    
    h1 {
      color: var(--primary);
      margin-bottom: 10px;
    }
    
    .status-card {
      background: white;
      border-radius: 8px;
      padding: 20px;
      margin-bottom: 20px;
      box-shadow: 0 2px 10px rgba(0,0,0,0.1);
    }
    
    .nav-links {
      display: flex;
      gap: 15px;
      margin-bottom: 20px;
    }
    
    .nav-links a {
      display: inline-block;
      padding: 10px 20px;
      background-color: var(--primary);
      color: white;
      text-decoration: none;
      border-radius: 5px;
      transition: background-color 0.3s;
    }
    
    .nav-links a:hover {
      background-color: #2980b9;
    }
    
  </style>
</head>
<body>
  <header>
    <h1>K9AY RX Loop Controller</h1>
  </header>
  
  <div class="status-card">
)");

  // Добавляем информацию о подключении
  if (server.client().localIP() == apIP) {
    Page += F("<p>🔵 Connected via Soft AP: <strong>");
    Page += softAP_ssid;
    Page += F("</strong></p>");
  } else {
    Page += F("<p>🟢 Connected to WiFi network: <strong>");
    Page += ssid;
    Page += F("</strong></p>");
  }

  Page += F(R"(
  </div>
  
  <div class="nav-links">
    <a href='/wifi'>WiFi Configuration</a>
    <a href='/switch'>Direction Control</a>
  </div>
  

)");
  // Завершаем страницу
  Page += F(R"(
</body>
</html>
)");

  // Отправляем страницу клиенту
  server.send(200, "text/html", Page);
}

void saveLabels() {
  EEPROM.begin(512);
  EEPROM.put(100, label0);
  EEPROM.put(100 + sizeof(label0), label1);
  EEPROM.put(100 + sizeof(label0) + sizeof(label1), label2);
  EEPROM.put(100 + sizeof(label0) + sizeof(label1) + sizeof(label2), label3);
  EEPROM.put(100 + sizeof(label0) + sizeof(label1) + sizeof(label2) + sizeof(label3), label4);
  EEPROM.put(100 + sizeof(label0) + sizeof(label1) + sizeof(label2) + sizeof(label3) + sizeof(label4), label5);
  EEPROM.put(100 + sizeof(label0) + sizeof(label1) + sizeof(label2) + sizeof(label3) + sizeof(label4) + sizeof(label5), label6);
  EEPROM.put(100 + sizeof(label0) + sizeof(label1) + sizeof(label2) + sizeof(label3) + sizeof(label4) + sizeof(label5) + sizeof(label6), label7);
  char ok[8 + 1] = "OK";
  EEPROM.put(100 + sizeof(label0) + sizeof(label1) + sizeof(label2) + sizeof(label3) + sizeof(label4) + sizeof(label5) + sizeof(label6) + sizeof(label7), ok);
  EEPROM.commit();
  EEPROM.end();
}

void handleWifi() {
  // Запрещаем кэширование страницы
  server.sendHeader("Cache-Control", "no-cache, no-store, must-revalidate");
  server.sendHeader("Pragma", "no-cache");
  server.sendHeader("Expires", "-1");

  // Формируем HTML страницу
  String Page = String(R"(
<!DOCTYPE html>
<html lang="en">
<head>
  <meta charset="UTF-8">
  <meta name="viewport" content="width=device-width, initial-scale=1.0">
  <title>WiFi Configuration - K9AY Controller</title>
  <style>
    :root {
      --primary: #3498db;
      --secondary: #2ecc71;
      --danger: #e74c3c;
      --dark: #2c3e50;
      --light: #ecf0f1;
    }
    
    body {
      font-family: 'Segoe UI', Tahoma, Geneva, Verdana, sans-serif;
      line-height: 1.6;
      color: var(--dark);
      max-width: 800px;
      margin: 0 auto;
      padding: 20px;
      background-color: #f5f7fa;
    }
    
    h1 {
      color: var(--primary);
      text-align: center;
      margin-bottom: 20px;
    }
    
    .status-card {
      background: white;
      border-radius: 8px;
      padding: 20px;
      margin-bottom: 20px;
      box-shadow: 0 2px 10px rgba(0,0,0,0.1);
    }
    
    .btn {
      border: none;
      color: white;
      padding: 8px 16px;
      text-align: center;
      text-decoration: none;
      display: inline-block;
      font-size: 14px;
      font-weight: 500;
      border-radius: 6px;
      cursor: pointer;
      transition: all 0.3s ease;
      min-width: 60px;
    }
    
    .btn-on {
      background-color: var(--secondary);
    }
    
    .btn-off {
      background-color: var(--danger);
    }
    
    .btn:hover {
      opacity: 0.9;
      transform: translateY(-1px);
    }
    
    table {
      width: 100%;
      border-collapse: collapse;
      margin: 15px 0;
      background: white;
      border-radius: 8px;
      overflow: hidden;
      box-shadow: 0 2px 10px rgba(0,0,0,0.1);
    }
    
    th, td {
      padding: 12px 15px;
      text-align: left;
      border-bottom: 1px solid #ddd;
    }
    
    th {
      background-color: var(--primary);
      color: white;
    }
    
    tr:hover {
      background-color: #f5f5f5;
    }
    
    form {
      background: white;
      padding: 20px;
      border-radius: 8px;
      box-shadow: 0 2px 10px rgba(0,0,0,0.1);
      margin: 20px 0;
    }
    
    input[type="text"],
    input[type="password"] {
      width: 100%;
      padding: 10px;
      margin: 8px 0;
      display: inline-block;
      border: 1px solid #ccc;
      border-radius: 4px;
      box-sizing: border-box;
    }
    
    input[type="submit"] {
      width: 100%;
      background-color: var(--primary);
      color: white;
      padding: 12px 20px;
      margin: 8px 0;
      border: none;
      border-radius: 4px;
      cursor: pointer;
      font-size: 16px;
    }
    
    input[type="submit"]:hover {
      background-color: #2980b9;
    }
    
    .ap-status {
      display: inline-block;
      padding: 4px 8px;
      border-radius: 4px;
      font-weight: bold;
    }
    
    .ap-on {
      background-color: var(--secondary);
      color: white;
    }
    
    .ap-off {
      background-color: var(--danger);
      color: white;
    }
    
    .footer {
      text-align: center;
      margin-top: 20px;
    }
    
    .footer a {
      color: var(--primary);
      text-decoration: none;
    }
    
    .footer a:hover {
      text-decoration: underline;
    }
  </style>
</head>
<body>
  <h1>WiFi Configuration</h1>
  
  <div class="status-card">
)");

  // Добавляем информацию о подключении
  if (server.client().localIP() == apIP) {
    Page += F("<p>🔵 Connected via <strong>Soft AP</strong>: ");
    Page += softAP_ssid;
    Page += F("</p>");
  } else {
    Page += F("<p>🟢 Connected to <strong>WiFi Network</strong>: ");
    Page += ssid;
    Page += F("</p>");
  }

  // Добавляем uptime
  Page += F("<p>Uptime: <strong>");
  Page += String(day) + "d " + String(hour) + "h " + String(minute) + "m " + String(sec) + "s";
  Page += F("</strong></p>");
  
  // Добавляем управление AP
  /*Page += F(R"(
    <p>
      <a href="APon" class="btn btn-on">ON</a>
      <a href="APoff" class="btn btn-off">OFF</a>
      Access Point Status: <span class="ap-status )");
  Page += (flag_off == 0 ? "ap-on\">ON" : "ap-off\">OFF");*/
  Page += F(R"(</span>
    </p>
  </div>
  
  <div class="status-card">
    <h3>SoftAP Configuration</h3>
    <table>
      <tr><th>Parameter</th><th>Value</th></tr>
      <tr><td>SSID</td><td>)");
  Page += softAP_ssid;
  Page += F(R"(</td></tr>
      <tr><td>IP Address</td><td>)");
  Page += WiFi.softAPIP().toString();
  Page += F(R"(</td></tr>
    </table>
  </div>
  
  <div class="status-card">
    <h3>WLAN Configuration</h3>
    <table>
      <tr><th>Parameter</th><th>Value</th></tr>
      <tr><td>SSID</td><td>)");
  Page += ssid;
  Page += F(R"(</td></tr>
      <tr><td>IP Address</td><td>)");
  Page += WiFi.localIP().toString();
  Page += F(R"(</td></tr>
    </table>
  </div>
  
  <div class="status-card">
    <h3>Available Networks</h3>
    <p>Click refresh if networks are missing</p>
    <table>
      <tr><th>Network Name</th><th>Signal</th></tr>
)");

  // Сканируем сети WiFi
  Serial.println("scan start");
  int n = WiFi.scanNetworks();
  Serial.println("scan done");
  
  if (n > 0) {
    for (int i = 0; i < n; i++) {
      Page += F("<tr><td>");
      Page += WiFi.SSID(i);
      if (WiFi.encryptionType(i) != ENC_TYPE_NONE) {
        Page += F(" <small>(secured)</small>");
      }
      Page += F("</td><td>");
      Page += WiFi.RSSI(i);
      Page += F(" dBm</td></tr>");
    }
  } else {
    Page += F("<tr><td colspan=\"2\">No WiFi networks found</td></tr>");
  }

  Page += F(R"(
    </table>
  </div>
  
  <form method='POST' action='wifisave'>
    <h3>Connect to Network</h3>
    <label for="n">Network SSID:</label>
    <input type="text" id="n" name="n" placeholder="Enter network name" required>
    
    <label for="p">Password:</label>
    <input type="password" id="p" name="p" placeholder="Enter password">
    
    <input type="submit" value="Connect">
  </form>
  
  <div class="footer">
    <a href="/">← Return to Home Page</a>
  </div>
</body>
</html>
)");

  server.send(200, "text/html", Page);
}

void handleNotFound() {
  String message = "File Not Found\n\n";
  message += "URI: ";
  message += server.uri();
  message += "\nMethod: ";
  message += (server.method() == HTTP_GET) ? "GET" : "POST";
  message += "\nArguments: ";
  message += server.args();
  message += "\n";

  for (uint8_t i = 0; i < server.args(); i++) {
    message += " " + server.argName(i) + ": " + server.arg(i) + "\n";
  }
  server.sendHeader("Cache-Control", "no-cache, no-store, must-revalidate");
  server.sendHeader("Pragma", "no-cache");
  server.sendHeader("Expires", "-1");
  server.send(404, "text/plain", message);
}

void handleWifiSave() {
  Serial.println("wifi save");
  server.arg("n").toCharArray(ssid, sizeof(ssid) - 1);
  server.arg("p").toCharArray(password, sizeof(password) - 1);
  server.sendHeader("Location", "wifi", true);
  server.sendHeader("Cache-Control", "no-cache, no-store, must-revalidate");
  server.sendHeader("Pragma", "no-cache");
  server.sendHeader("Expires", "-1");
  server.send(302, "text/plain", "");    // Empty content inhibits Content-length header so we have to close the socket ourselves.
  server.client().stop(); // Stop is needed because we sent no content length
  saveCredentials();
  connect = strlen(ssid) > 0; // Request WLAN connect with new credentials if there is a SSID
}
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
void loop(void){
  digitalWrite(OE_pin, LOW);
  if (connect) {
    Serial.println("Connect requested");
    connect = false;
    connectWifi();
    lastConnectTry = millis();
  }
  {
    unsigned int s = WiFi.status();
    if (s == 0 && millis() > (lastConnectTry + 60000)) {
      connect = true;
    }
    if (status != s) { // WLAN status change
      Serial.print("Status: ");
      Serial.println(s);
      status = s;
      if (s == WL_CONNECTED) {
        /* Just connected to WLAN */
        Serial.println("");
        Serial.print("Connected to ");
        Serial.println(ssid);
        Serial.print("IP address: ");
        Serial.println(WiFi.localIP());
        digitalWrite(LED_pin, HIGH);
        flagAP=1;
      } else if (s == WL_NO_SSID_AVAIL) {
        digitalWrite(LED_pin, LOW);
        flagAP=0;
        WiFi.disconnect();
      }
    }
  }
  if (flagAP==1) 
  {
    tim++; 
    if (tim==1000) {sec++; tim=0;}
    if (sec==60) {minute++; sec=0;}
    if (minute==60) {hour++; minute=0;}
    if (hour==24) {day++; hour=0;}
  }
  if ((flagAP==0)&&(tim>0)) tim=sec=minute=hour=day=0;
  server.handleClient();
  delay(1);
}

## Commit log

2023-02-22 corrected SPI init
2025-03-23 add revision 2 in KiCad
    [K9AY_switch-B_Cu.gbr, K9AY_switch-B_Mask.gbr, K9AY_switch-B_Paste.gbr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]
2026-10-15 Rework firmware web interface, update README and manuals
    Firmware:
    - fix memory leak and double HTTP responses in switch handlers
    - fix SSID/password length, escape SSIDs (XSS), working captive portal
    - non-blocking WiFi connect with retry logic, async network scan
    that does not abort a connection attempt
    - AJAX UI with compass layout, JSON API (/api/state, /set), mDNS k9ay.local
    - direction labels page, state saved to EEPROM 30 s after last change
    - SoftAP name from chip ID; SoftAP can be disabled while connected to
    WLAN and turns on automatically when the saved network is unavailable
    - optional HTTP authentication, migration of old WiFi credentials
    Docs: new README and RU/EN manuals (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
2026-10-15 Update KiCad project, gerbers and pictures
    - updated schematic, PCB, BOM, gerbers and plots
    - new photos: k1, mosfet, pwr; updated direction diagram
    - ignore KiCad backups, *.tar.gz and k9ay_v5.zip
